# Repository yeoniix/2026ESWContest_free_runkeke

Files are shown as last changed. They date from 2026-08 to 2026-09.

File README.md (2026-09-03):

# HeatSentry TAC

**군 집단훈련 온열위험 대응 시스템** — 감지 · 자가 개입 · 관제 전파를 한 장비에서 완결하는
현장 안전 웨어러블 시스템

> 제24회 임베디드SW경진대회 자유공모 출품작 · 팀 **런크크(RUNKEKE)**
> 개발기간 2026.07.01 ~ 2026.09.03

```
센서 취득 → RiskIndex → 상태 판정(FSM) → 자동 냉각 → 재평가 → (미회복 시 상향) → SOS → 감사 로그
```

HeatSentry는 손목 웨어러블의 생체신호, 허리의 능동 냉각, 로컬 게이트웨이, 관제 대시보드를
하나의 폐루프로 묶는다. 위험도가 임계를 넘으면 **누구의 지시도 기다리지 않고** 벨트가 팬을
돌리고 장갑 OLED·진동으로 착용자에게 알리며, 같은 판정 결과가 LoRa로 관제까지 전파된다.

> [!IMPORTANT]
> **RiskIndex와 피부온도는 의료 진단값이 아니다.** 현장 경보와 냉각 우선순위를 정하기 위한
> 상대 위험도이며, 열사병 의심 증상·의식 변화·무응답이 있으면 장치 점수와 무관하게 현장
> 응급절차가 항상 우선한다.

---

스크린샷 2026-09-03 오전 10 31 55

스크린샷 2026-09-03 오전 10 32 06

스크린샷 2026-09-03 오전 10 32 22

스크린샷 2026-09-03 오전 10 32 43

스크린샷 2026-09-03 오전 10 33 26

스크린샷 2026-09-03 오전 10 33 35

스크린샷 2026-09-03 오전 10 33 56

스크린샷 2026-09-03 오전 10 34 07

스크린샷 2026-09-03 오전 10 34 17

스크린샷 2026-09-03 오전 10 34 25

스크린샷 2026-09-03 오전 10 34 34

스크린샷 2026-09-03 오전 10 34 41

스크린샷 2026-09-03 오전 10 34 51

스크린샷 2026-09-03 오전 10 35 01

스크린샷 2026-09-03 오전 10 35 11

스크린샷 2026-09-03 오전 10 35 21

스크린샷 2026-09-03 오전 10 35 31

스크린샷 2026-09-03 오전 10 35 39

스크린샷 2026-09-03 오전 10 35 48

스크린샷 2026-09-03 오전 10 35 59

## 목차

1. [왜 만들었나](#왜-만들었나)
2. [시스템 구성](#시스템-구성)
3. [저장소 구조](#저장소-구조)
4. [빠르게 돌려보기](#빠르게-돌려보기)
5. [실물 하드웨어 연동](#실물-하드웨어-연동)
6. [RiskIndex 계산](#riskindex-계산)
7. [상태 판정(FSM)](#상태-판정fsm)
8. [게이트웨이 API](#게이트웨이-api)
9. [데이터 무결성과 감사 로그](#데이터-무결성과-감사-로그)
10. [보안·운영 설정](#보안운영-설정)
11. [시험](#시험)
12. [안전 경계와 적용 범위](#안전-경계와-적용-범위)
13. [알려진 차이와 남은 작업](#알려진-차이와-남은-작업)
14. [문서 · 팀](#문서--팀)

---

## 왜 만들었나

2024년 5월 육군 12사단 훈련병 사망 사고에서, 우리 팀은 집단훈련 온열 질환 사고를 세 가지
문제로 정의했다.

| 문제 | 이 저장소의 대응 |
| --- | --- |
| **주관적 오판** — 개인의 위험 신호가 "꾀병"으로 묵살될 여지 | 센서값과 RiskIndex를 위·변조 탐지 가능한 해시체인 로그로 관제에 전송해, 주관이 아닌 수치로 판단하게 한다 |
| **자가진단 실패** — 열 스트레스는 당사자가 스스로 인지하기 어렵다 | 장갑 손등 OLED에 상태를 상시 표시하고, 임계 초과 시 진동 모터가 즉시 작동한다 |
| **초기 개입 수단 부재** — 이상을 감지해도 즉시 취할 물리적 수단이 없다 | 지휘관 개입 이전에 허리 장착형 냉각 팬을 자동 구동한다 |

개인의 통제 아래 놓인 기존 웨어러블과 달리, **집단 통제가 필요한 특수 환경**에서 쓸 수 있는
반응형 경보 시스템을 목표로 했다.

### 기존 개인용 웨어러블과의 차이

| 비교 항목 | 일반적인 개인 경고형 웨어러블 | HeatSentry |
| --- | --- | --- |
| 위험 대응 | 알림 제공 후 종료 | OLED·진동 경고 → 팬 1개 → 팬 2개 → 관제 전파 |
| 통신 두절 | 서버 연결이 끊기면 관제·대응 제한 | 벨트가 로컬에서 계속 판정하고 팬을 독립 제어 |
| 판정 구조 | 서버 판정에 의존 | 벨트가 단독 판정자 — 게이트웨이는 재계산하지 않고 전달만 하며, 해석 불가 값은 오류로 남긴다 |
| 센서 고장 | 누락값으로 위험을 과소평가 | 고장 센서 제외 + 가중치 재정규화 + `SENSOR_LIMITED` 별도 표시 |
| 통신 효율 | Wi-Fi·서버 연결 중심 | 35바이트 LoRa 패킷으로 생체·상태·GPS 원거리 전송 |
| 사후 기록 | 수정 가능한 일반 로그 | SHA-256 해시체인으로 최초 변경 지점 탐지 |

---

## 시스템 구성

```
 ┌──────────────────┐  ESP-NOW   ┌──────────────────┐   LoRa    ┌──────────────┐  HTTP  ┌───────────┐
 │   손목 노드       │ ─ 28B/1s ─▶│    벨트 노드      │─ 35B/2s ─▶│ LoRa 수신기   │───────▶│ 게이트웨이 │
 │  ESP32 Dev       │◀─ 12B/0.5s │  Heltec ESP32-S3 │  922.3MHz └──────────────┘        │ FastAPI   │
 │                  │            │                  │                                   └─────┬─────┘
 │ MAX30102  심박    │            │ 로컬 FSM 판정     │                                    WS /ws/live
 │ TMP117    피부온도 │            │ ATGM336H GPS     │                                    REST /api/v2
 │ GSR       피부전도 │            │ 비상 버튼         │                                         │
 │ SSD1306   OLED   │            │ 팬 ×2 (PWM)      │                                   ┌─────▼─────┐
 │ 진동 모터         │            │ LoRa 송신         │                                   │  대시보드  │
 └──────────────────┘            └──────────────────┘                                   │ React+Vite│
                                                                                        └───────────┘
   판정하지 않는다.                실물 경로의 단독 판정자.            위험도를 다시 계산하지        현장 팬을 제어할 수 없고
   벨트가 회신한 상태를             LoRa가 끊겨도 팬과 OLED를          않고 저장·전파만 한다.       응급도 해제할 수 없다.
   띄우고 경고 시 진동.             혼자 계속 구동한다.                                           확인 기록만 남긴다.
```

### 통신 규격

| 링크 | 내용 | 주기 | 정의 위치 |
| --- | --- | --- | --- |
| ESP-NOW 손목→벨트 | `SensorPacket` 28B (bpm, temp, gsr, gsrDiff, ir, finger, seq) | 1초 | [firmware/glove_esp32/glove_esp32.ino](firmware/glove_esp32/glove_esp32.ino) |
| ESP-NOW 벨트→손목 | `DisplayPacket` 12B (state, cause, fanPercent, bpm, skinTemp, flags) | 0.5초 | [firmware/glove_esp32/display_protocol.h](firmware/glove_esp32/display_protocol.h) |
| LoRa 벨트→수신기 | `TelemetryPacket` 35B · SF7 · BW 125kHz · CR 4/5 · 922.3MHz. 생체값 + GPS + 벨트 판정(state·cause·냉각단계·위험도) | GPS fix 시 단축 | [firmware/lora_get/esplora_get.ino](firmware/lora_get/esplora_get.ino) · [glove_packets.py](heatsentry/common/glove_packets.py) |
| HTTP 브리지→게이트웨이 | `POST /ingest/telemetry` (TelemetryV2 JSON) | 패킷마다 | [heatsentry/common/schema.py](heatsentry/common/schema.py) |
| WebSocket 게이트웨이→UI | `/ws/live` — `snapshot` / `telemetry` / `event` / `command_ack` | ≤1초 | [heatsentry/server/ws.py](heatsentry/server/ws.py) |

35바이트 안에 벨트의 판정까지 담기 위해, DHT 제거로 비게 된 두 16비트 자리를 재활용한다.

```
state_cause_word = (DeviceState << 8) | CauseCode
stage_risk_word  = (CoolingStage << 8) | RiskIndex
```

패킷 크기는 펌웨어의 `static_assert`와 파이썬 디코더가 서로 검증하며,
[tests/test_display_protocol_sync.py](tests/test_display_protocol_sync.py)가 장갑·벨트 두
헤더 파일과 파이썬 enum의 코드 정의가 어긋나지 않는지 확인한다.

> [!WARNING]
> 현재 `firmware/belt_heltec/belt_heltec.ino`에 **벨트 펌웨어가 없다** — 장갑 스케치로
> 덮어써진 상태다. LoRa 송신 주기·송신 출력 등 벨트 측 수치는 저장소에서 확인할 수 없다.
> [알려진 차이](#알려진-차이와-남은-작업) 참고.

### 서브시스템 책임

| 서브시스템 | 책임 | 코드 |
| --- | --- | --- |
| SU-W 손목 노드 | 센서 취득·품질 검사, OLED 표시, 진동 | `firmware/glove_esp32/`, `heatsentry/simulator/wrist_node.py` |
| SU-B 허리 노드 | 로컬 위험 판정, 팬 PWM 제어, GPS, 비상 버튼, LoRa 송신 | `firmware/belt_heltec/`, `heatsentry/simulator/belt_node.py` |
| SU-E 환경 노드 | EnvHeatProxy (WBGT와는 별개 지표, 시뮬레이터 전용) | `heatsentry/simulator/env_node.py` |
| SU-G 게이트웨이 | 패킷 디코딩·저장·해시체인·역할 분리·WebSocket 전파 (재판정하지 않음) | `heatsentry/server/` |
| SU-D 대시보드 | 상태 카드, 위험도 추이, GPS 지도, 이벤트·확인 기록 | `dashboard/` |

---

## 저장소 구조

파이썬 코드는 전부 `heatsentry/` 패키지 하나에 있고, 그 바깥에는 파이썬이 아닌 것만 둔다 —
임베디드 펌웨어, 웹 대시보드, 문서, 시험.

```
heatsentry/          파이썬 패키지 (pip install -e . 로 설치 가능)
├─ common/           패킷 정의·해시체인·CRC16·오류코드·게이트웨이 스키마
│  ├─ packets.py         HS_STATUS / COOL_CMD / COOL_ACK 바이너리 레이아웃, DeviceState
│  ├─ glove_packets.py   실물 35B TelemetryPacket 디코더, 벨트 상태·원인 코드
│  ├─ schema.py          TelemetryV2 (게이트웨이 ↔ 대시보드 JSON 계약)
│  └─ hash_chain.py      SHA-256 이벤트 해시체인
├─ algorithm/        위험도 판정
│  ├─ risk_config.py     가중치·임계값·냉각 단계 표 (형상관리 대상 숫자 전부)
│  ├─ risk_engine.py     RiskIndex v0.3 계산 + 품질 게이트
│  ├─ baseline.py        개인 기준선(3~5분) 생성
│  ├─ fsm.py             C0~C4 냉각 단계 · DeviceState · 명령 중재
│  ├─ hardware_adapter.py 실물 3특징 프로필용 어댑터
│  └─ display_status.py  OLED 2줄 문구 생성
├─ simulator/        결정적 노드 시뮬레이터 (실물 펌웨어의 레퍼런스 구현)
│  └─ run_demo.py        T01~T08·T10 시나리오 러너
└─ server/           게이트웨이 (FastAPI)
   ├─ main.py            앱 조립 · CORS · /ws/live
   ├─ routes_ingest.py   /ingest/* (장치 키 인증 · 시퀀스 중복 제거)
   ├─ routes_api_v2.py   /api/v2/* (역할 기반 확인·해제·내보내기·설정)
   ├─ lora_adapter.py    35B 패킷 → TelemetryV2 변환 (벨트 판정을 그대로 전달)
   ├─ state.py / db.py   메모리 상태 + SQLite 저장 + 해시체인
   └─ ws.py              WebSocket 브로드캐스트

firmware/            임베디드 C/C++
├─ glove_esp32/      장갑 ESP32 스케치 + OLED 표시 프로토콜 헤더
├─ belt_heltec/      벨트 Heltec LoRa 스케치 (로컬 판정 · 팬 제어) + 표시 프로토콜 헤더
└─ lora_get/         LoRa 수신기 스케치 (35B를 시리얼로 넘긴다)

dashboard/           React + TypeScript + Vite 관제 대시보드
docs/hardware/       실물 배선 · 핀맵 · 조립 · 브리지 연동 가이드, CAD 소스
tests/               pytest 80건
pyproject.toml       패키지 경계와 pytest 설정
requirements.txt     고정 의존성
```

임계값·가중치 같은 형상관리 대상 숫자는 [heatsentry/algorithm/risk_config.py](heatsentry/algorithm/risk_config.py)
한 파일에 모여 있다. FSM은 이 파일의 표만 읽으므로, 냉각 단계 기준을 바꿀 때 `fsm.py`는
건드리지 않는다.

---

## 빠르게 돌려보기

하드웨어 없이 시뮬레이터만으로 감지 → 냉각 → 관제 전파 폐루프 전체를 재현할 수 있다.
터미널 3개가 필요하다.

### 1) 게이트웨이 (FastAPI)

```bash
python3 -m venv .venv
source .venv/bin/activate       # Windows: .venv\Scripts\activate
pip install -r requirements.txt
uvicorn heatsentry.server.main:app --reload --port 8000
```

`http://127.0.0.1:8000/docs`에서 OpenAPI 문서를 확인할 수 있다.

### 2) 노드 시뮬레이터

```bash
# 새 터미널, 같은 가상환경
python -m heatsentry.simulator.run_demo --scenario T03 --fast
```

| 옵션 | 기본값 | 설명 |
| --- | --- | --- |
| `--scenario` | `T03` | `T01`~`T08`, `T10` 중 하나 (정의는 [scenarios.py](heatsentry/simulator/scenarios.py)) |
| `--gateway-url` | `http://127.0.0.1:8000` | 게이트웨이 주소 |
| `--device-id` | `HS-W-001` | 장치 ID |
| `--fast` | off | 3~5분 걸리는 기준선 측정을 6~9초로 단축 (**개발용**, 실제 시연에는 쓰지 않는다) |
| `--sleep` | `1.0` | tick 사이 실제 대기 시간(초). `0`이면 최대 속도 |
| `--dt` | `1.0` | tick 하나가 나타내는 시뮬레이션 시간(초) |
| `--cycles` | `3` | T10 통합 시나리오 반복 횟수 |

주요 시나리오:

| ID | 검증 내용 |
| --- | --- |
| T01 | 기준선 안정 → NORMAL 유지 |
| T02 | PPG/EDA 동시 품질 저하 → `valid_weight < 0.60` → `SENSOR_LIMITED` |
| T03 | RiskIndex ≥ 80이 10초 지속 → 냉각 C1 진입 (CTL-001) |
| T04 | 냉각 명령 ACK 손실 → 재전송 |
| T05 | 팬 과전류 → 팬 OFF (E301) |
| T06 | 90→70 회복 → 30초 후 단계 하향 |
| T07 | C2가 60초 이상 미회복 → C3, 지휘관 확인 후에만 하향 |
| T08 | 낙상+무동작+무응답 → HardTrigger → 즉시 EMERGENCY |
| T10 | 폐루프 통합 반복 + 로그 변조 시 해시체인 불일치 검출 |

### 3) 대시보드 (React + Vite)

```bash
cd dashboard
npm install
npm run dev
```

`http://localhost:5173`에서 실시간 장치 카드, RiskIndex 추이, 냉각 상태, GPS 지도,
이벤트 로그(해시체인), 확인/응급 해제 콘솔을 볼 수 있다. 우측 상단 역할 선택기로
`observer` / `commander` / `tester` / `maintainer`를 바꿔가며 권한 분리를 확인한다(HMI-001).

선택 설정 — `dashboard/.env.local`:

```bash
VITE_GATEWAY_URL=http://127.0.0.1:8000   # 기본값
VITE_KAKAO_MAP_APP_KEY=<카카오맵 JS 키>   # 없으면 지도 대신 안내 문구 표시
```

---

## 실물 하드웨어 연동

### 부품

| 노드 | 부품 | 역할 |
| --- | --- | --- |
| 손목 | ESP32 Dev Module | 메인 MCU |
| | MAX30102 | PPG · 심박 |
| | TMP117 | 피부 온도 |
| | GSR Sensor | 피부 전도 |
| | SSD1306 OLED 128×64 | 상태 표시 |
| | 진동 모터 | 경고 |
| 벨트 | Heltec ESP32-S3 (LoRa 915) | 로컬 판정 · LoRa 송신 |
| | ATGM336H | GPS 측위 |
| | 12mm 버튼 | 비상 입력 |
| | 40×40mm Fan ×2 | 능동 냉각 (PWM 5kHz · 8bit) |

기구부는 Fusion 360으로 설계해 3D 프린팅했다 — 듀얼 팬 모듈, 유도판, 상부 덕트, 팬 교체가
가능한 분리형 하우징. CAD 파라메트릭 소스는 [docs/hardware/cad/](docs/hardware/cad/)에 있다.

### 펌웨어 빌드

Arduino IDE 2.x + ESP32 Arduino Core로 세 스케치를 각각 업로드한다.

| 스케치 | 보드 |
| --- | --- |
| [firmware/glove_esp32/glove_esp32.ino](firmware/glove_esp32/glove_esp32.ino) | ESP32 Dev Module |
| [firmware/belt_heltec/belt_heltec.ino](firmware/belt_heltec/belt_heltec.ino) | Heltec WiFi LoRa 32 (V3) — **현재 소스 유실 상태** |
| [firmware/lora_get/esplora_get.ino](firmware/lora_get/esplora_get.ino) | Heltec WiFi LoRa 32 (V3) |

벨트와 수신기의 LoRa 파라미터(922.3MHz · SF7 · BW 125kHz · CR 4/5)는 **반드시 동일해야**
한다. 자세한 배선·핀맵·조립 순서는 [docs/hardware/hardware_integration_kr.md](docs/hardware/hardware_integration_kr.md).

### 수신기 → 게이트웨이 브리지

LoRa 수신기 스케치는 35바이트를 검증한 뒤 시리얼로 넘긴다. 파이썬 쪽에는 이를 관제
텔레메트리로 바꾸는 어댑터가 준비돼 있다.

```python
import requests
from heatsentry.server.lora_adapter import LoRaTelemetryAdapter

adapter = LoRaTelemetryAdapter()

def handle_packet(payload: bytes, rssi: int, snr: int) -> None:
    telemetry = adapter.convert(payload, rssi_dbm=rssi, snr_db=snr)
    requests.post("http://127.0.0.1:8000/ingest/telemetry",
                  json=telemetry.model_dump(), timeout=3).raise_for_status()
```

> [!NOTE]
> **USB 시리얼을 읽어 위 함수를 호출하는 상주 프로세스는 아직 저장소에 없다.** 디코더·어댑터·
> 게이트웨이 수신단은 모두 구현·시험되어 있고, 남은 것은 시리얼 루프 하나다. 권장 시리얼 한 줄
> 형식과 전체 예제는 [docs/hardware/hardware_integration_kr.md](docs/hardware/hardware_integration_kr.md) 12장에 있다.

---

## RiskIndex 계산

RiskIndex v0.3 엔진은 **시뮬레이터 경로(손목 노드)** 가 쓴다. 실물 경로에서는 벨트가 자체
위험점수를 계산해 패킷에 실어 보내므로 게이트웨이가 이 엔진을 다시 돌리지 않는다
([판정 주체](#판정-주체--경로에-따라-다르다) 참고).

세 개 이상의 생체·환경 특징을 각각 0~1로 정규화해 가중 평균한다. 핵심은 **분모가 상수가
아니라 "지금 살아있는 가중치의 합"**이라는 점이다. 센서 하나가 죽어도 0으로 희석되지 않고,
남은 센서끼리 다시 정규화한다.

```
RiskIndex = 100 × Σ(wᵢ · qᵢ · featureᵢ) / Σ(wᵢ · qᵢ)

  w       가중치
  q       센서 품질 (0~1, 게이트 미달이면 0)
  feature 0~1로 정규화(clamp)한 특징

valid_weight = Σ(wᵢ · qᵢ)
  < 0.60 → SENSOR_LIMITED 플래그
  = 0    → 판정 불가 (risk_index = 255)
```

### 가중치 — 두 개의 프로필

`risk_config.py`는 설계 기준과 실물 하드웨어, 두 벌의 가중치를 갖는다.

| 특징 | 정규화 | `DEFAULT_CONFIG`<br>(설계 · 시뮬레이터) | `HARDWARE_CONFIG`<br>(실물 3특징) |
| --- | --- | --- | --- |
| `HR_dev` 심박 편차 | (BPM − 기준선) / MAD ÷ 4 | 0.25 | **0.45** |
| `SkinTemp_slope` 온도 상승률 | (°C/분) ÷ 0.3 | 0.20 | **0.37** |
| `EDA_delta` 발한 변화 | GSR 변화량 ÷ 300 | 0.10 | **0.18** |
| `HRV_suppression` | RMSSD 억제 | 0.10 | 0 — 패킷에 RMSSD 없음 |
| `ActivityLoad` | IMU 활동량 | 0.15 | 0 — IMU 미탑재 |
| `EnvHeatProxy` | 환경 열부하 | 0.20 | 0 — DHT 센서 제거 |

실물 패킷에는 6특징 중 3개가 오지 않는다(DHT는 하드웨어에서 제거됐고, 그 자리는 벨트 판정
전송에 재활용된다). 설계 가중치를 그대로 쓰면 살아있는 가중치 합이
0.55로 `min_valid_weight`(0.60)에 항상 미달해 실물 장비가 무조건 `SENSOR_LIMITED`로 보고되는
문제가 있었다. 그래서 남은 3특징에 가중치를 비례 재분배해 합이 1.00이 되게 했다. RiskIndex는
어차피 `valid_weight`로 나눠 재정규화하므로 **점수 자체는 달라지지 않고**, `valid_weight`의
의미만 달라진다 — 이제 0.60 미달은 "설계상 없는 센서" 때문이 아니라 손가락 이탈·온도 정지 같은
**실제 품질 저하**일 때만 발생한다.

### 품질 게이트

| 코드 | 조건 | 제외되는 특징 |
| --- | --- | --- |
| `E101` | PPG 품질 < 70 | `HR_dev`, `HRV_suppression` |
| `E102` | EDA 접촉 손실 (품질 < 40) | `EDA_delta` |
| `E103` | 피부온도 3초 이상 갱신 없음 | `SkinTemp_slope` |
| `E105` | 환경 센서 품질 < 50 | `EnvHeatProxy` |

게이트를 통과하면 `q = 품질/100`으로 비례 반영하고, 미달하면 `q = 0`으로 계산에서 제외한 뒤
오류코드를 `active_errors`에 남긴다. 개인 기준선은 유효 착용 3~5분 구간에서 생성하며, 기준선이
없으면 RiskIndex를 계산하지 않고 `BASELINE` 상태로 보고한다.

---

## 상태 판정(FSM)

상태 코드는 펌웨어·게이트웨이·대시보드가 **하나의 정의를 공유한다.** 벨트가 보낸 값을
관제가 다른 뜻으로 읽는 일이 없도록, `firmware/*/display_protocol.h`의 enum과
`heatsentry/common/glove_packets.py`의 파이썬 enum이 이름·값 모두 같아야 하며
[tests/test_display_protocol_sync.py](tests/test_display_protocol_sync.py)가 이를 검사한다.

### DeviceState — 지금 어떤 상황인가

| 값 | 상태 | 조건 |
| --- | --- | --- |
| 0 | `BOOT` | 부팅 |
| 1 | `BASELINE` | 기준선 미완성 → RiskIndex 미계산 |
| 2 | `NORMAL` | C0이면서 경고 없음 |
| 3 | `CAUTION` | 경고 활성 (진입 60 · 10초 / 해제 55 · 30초) |
| 4 | `COOLING` | 냉각 단계가 C1 이상 |
| 5 | `EMERGENCY` | 비상 래치 걸림 |
| 6 | `SENSOR_CHECK` | 손가락 미착용 · BPM 0 · 데이터 무효 |

### 냉각 단계 — 팬을 얼마나 트는가

상태와 별개로 `CoolingStageCode`(C0~C4)가 함께 전송된다. 정의는
[risk_config.py](heatsentry/algorithm/risk_config.py)의 `CoolingStageConfig` 표 하나뿐이다.

| 단계 | 진입 조건 | 해제 조건 | 팬 |
| --- | --- | --- | --- |
| C0 | 최하단 | — | 0% |
| C1 | risk ≥ 80 · 10초 | risk < 70 · 30초 | 50% |
| C2 | risk ≥ 90 · 10초 | risk < 80 · 30초 | 100% |
| C3 | risk ≥ 90 · 60초 | risk < 85 · 60초 **+ 지휘관 확인** | 100% |
| C4 | risk ≥ 95 · 즉시 | **자동 해제 없음** | 100% |

C2와 C3가 같은 100%인 것은, 실제 블로워의 저출력 구간이 체감 냉각 효과가 작아 현장 제어를
OFF → 50% → 100% 두 출력 단계로 단순화했기 때문이다. 두 단계의 구분은 출력이 아니라 **위험
지속 시간과 경보 수준**에 있다.

`fsm.py`는 단계 이름조차 코드에 두지 않는다 — 최하단·최상단과 "자동 해제 조건이 없는
비상 단계"를 모두 위 표에서 유도하므로, 냉각 기준을 바꿀 때 고칠 파일은 `risk_config.py`
하나다. [tests/test_fsm.py](tests/test_fsm.py)가 임계값을 바꾼 설정으로 이를 회귀 검증한다.

Fail-safe: 링크 10초 두절 시 저하 모드, 팬 안전 타이머 60초, 명령 ACK 타임아웃 500ms ·
최대 3회 재전송.

### 판정 주체 — 경로에 따라 다르다

| 경로 | 판정 주체 | 게이트웨이의 역할 |
| --- | --- | --- |
| **실물 하드웨어** (LoRa 35B) | **벨트 노드** | 재계산하지 않고 전달만 한다 |
| **시뮬레이터** (HTTP) | 손목 노드 (RiskIndex v0.3 + FSM) | 재계산하지 않고 저장·전파만 한다 |

두 경로 모두 게이트웨이는 **판정을 다시 내리지 않는다.** 특히 실물 경로에서 벨트가 단독
판정자인 이유는, LoRa가 끊겨도 팬과 장갑 OLED가 계속 동작해야 하기 때문이다. 현장에서 실제로
팬을 돌린 근거와 관제 화면의 값이 갈리면 사고 조사에서 어느 쪽도 신뢰할 수 없게 되므로,
`lora_adapter.py`는 벨트가 보낸 `DeviceState` · `CoolingStage` · `RiskIndex` · `Cause`를
그대로 옮긴다.

대신 **값이 해석 불가일 때 조용히 넘어가지 않는다.**

| `active_errors` | 조건 | 처리 |
| --- | --- | --- |
| `STATE_INVALID` | 모르는 상태 코드 | `SENSOR_CHECK`으로 낮춘다 |
| `COOLING_STAGE_INVALID` | 모르는 냉각 단계 | C0으로 낮춘다 |
| `RISK_INVALID` | 위험도가 0~100 범위 밖 | `risk_index = 255`(판정 불가) |
| `SENSOR_CHECK` | 손가락 미착용 · 장갑 데이터 무효 | 그대로 표시 |

### 비상 상태 해제

`hard_trigger`(낙상+무동작 / SOS)로 걸린 래치는 **자동으로 풀리지 않는다.**
`close_emergency()`는 `/api/v2/emergency/{id}/close` 핸들러가 현장 확인자 정보와 함께
명시적으로 호출할 때만 실행되며, 이 엔드포인트는 `commander` 역할을 요구한다. 해제 직후에도
팬을 즉시 끄지 않고 한 단계 아래(C3)를 유지한다.

## 게이트웨이 API

| 메서드 | 경로 | 권한 | 설명 |
| --- | --- | --- | --- |
| `POST` | `/ingest/telemetry` | 장치 키 | 텔레메트리 수신 (시퀀스 증가분만 반영) |
| `POST` | `/ingest/event` | 장치 키 | 장치 이벤트 → 해시체인 기록 |
| `POST` | `/ingest/command_ack` | 장치 키 | 냉각 명령 ACK |
| `GET` | `/api/v2/devices` | 전체 | 장치별 최신 상태 |
| `GET` | `/api/v2/events` | 전체 | 이벤트 로그 (해시 포함) |
| `GET` | `/api/v2/alerts` | 전체 | 경보 목록 |
| `GET` | `/api/v2/emergency` | 전체 | 응급 목록 |
| `POST` | `/api/v2/alerts/{id}/ack` | `commander` | 알림 확인 |
| `POST` | `/api/v2/emergency/{id}/close` | `commander` | 응급 해제 (현장 확인자 기록 필수) |
| `POST` | `/api/v2/export` | `tester` | 이벤트 CSV/JSON 내보내기 |
| `PUT` | `/api/v2/config` | `maintainer` | 설정 변경 (HMAC-SHA256 서명 검증) |
| `WS` | `/ws/live` | observer 수준 | `snapshot` → `telemetry`/`event`/`command_ack` 스트림 |

역할은 `X-HS-Role`, 행위자는 `X-HS-Actor`, 장치 키는 `X-HS-Device-Key` 헤더로 전달한다.

> [!WARNING]
> `heatsentry/server/auth.py`의 역할 검사는 **프로덕션 인증이 아니다.** 대회 MVP 단계에서
> "권한이 분리되어 있어야 한다"는 구조를 먼저 세워둔 헤더 기반 placeholder이며, 실사용 전에는
> 서명된 토큰으로 교체해야 한다. `/api/v2/config` PUT만은 요구사항상 HMAC 서명 검증을 최소
> 구현해 두었다.

---

## 데이터 무결성과 감사 로그

모든 경보·명령·ACK·확인 기록은 SQLite에 저장되면서 해시체인으로 묶인다.

```
event_hash = SHA256( previous_hash || canonical_json(event_without_hash) )
canonical_json: UTF-8 · sorted keys · no whitespace · 소수점 6자리 고정
genesis previous_hash = "0" * 64
```

체인 중간의 한 건이라도 수정되면 그 지점부터 해시가 어긋나므로 **최초 변경 지점을 특정할 수
있다.** T10 시나리오가 실제로 로그를 변조해 불일치 검출을 확인한다. `/api/v2/export`로
`seq`, `gateway_utc`, `event_hash`, `previous_hash`를 포함한 CSV/JSON을 내보내 외부에서 재검증할
수 있고, 내보내기 행위 자체도 감사 기록에 남는다.

기본 DB 경로는 `heatsentry/heatsentry_gateway.db`이며 `HEATSENTRY_DB_PATH`로 바꿀 수 있다.
보존 정책과 스키마는 [db.py](heatsentry/server/db.py), 체인 계산은 [hash_chain.py](heatsentry/common/hash_chain.py)에 있다.

---

## 보안·운영 설정

실장 환경에서는 장치별 비밀키를 반드시 등록한다. **키가 비어 있으면 시뮬레이터 호환을 위한
개발 모드이며 `/ingest/*` 인증이 수행되지 않는다.**

```bash
export HEATSENTRY_DEVICE_KEYS='{"HS-W-001":"change-this-device-secret"}'
export HEATSENTRY_DEVICE_KEY='change-this-device-secret'   # 시뮬레이터 실행 터미널
export HEATSENTRY_CONFIG_SECRET='change-this-config-secret'
export HEATSENTRY_CORS_ORIGINS='http://127.0.0.1:5173'
export HEATSENTRY_DB_PATH='/var/lib/heatsentry/gateway.db'
```

| 환경변수 | 기본값 | 용도 |
| --- | --- | --- |
| `HEATSENTRY_DEVICE_KEYS` | `{}` (인증 없음) | 장치 ID → 비밀키 JSON 맵 |
| `HEATSENTRY_DEVICE_KEY` | 없음 | 시뮬레이터가 보낼 키 |
| `HEATSENTRY_CONFIG_SECRET` | `dev-only-insecure-secret` | `/api/v2/config` HMAC 키 |
| `HEATSENTRY_CORS_ORIGINS` | `http://127.0.0.1:5173,http://localhost:5173` | 허용 오리진 (쉼표 구분) |
| `HEATSENTRY_DB_PATH` | `heatsentry/heatsentry_gateway.db` | SQLite 경로 |

장치 키가 설정되면 모든 `/ingest/*` 요청은 `X-HS-Device-Key`가 일치해야 한다. 텔레메트리는
장치별 `sequence`가 증가할 때만 반영되므로, 재전송이 현재 상태나 감사 이벤트를 중복으로
덮어쓰지 않는다.

---

## 시험

```bash
# 파이썬 — 80건
pytest -q

# 대시보드 — 타입체크 · 빌드 · 린트
cd dashboard
npm run build
npx eslint .
```

| 파일 | 건수 | 검증 대상 |
| --- | --- | --- |
| `test_fsm.py` | 13 | 냉각 단계 승급·강등, 히스테리시스, 비상 래치, 명령 중재, 임계값 하드코딩 금지 |
| `test_gateway_api.py` | 10 | REST v2, 역할 분리, 장치 키, 시퀀스 중복 제거 |
| `test_hardware_risk_adapter.py` | 8 | 실물 3특징 프로필, 가중치 재정규화 |
| `test_scenarios_integration.py` | 8 | T01~T10 폐루프 통합 |
| `test_lora_adapter.py` | 9 | 35B → TelemetryV2 변환, 벨트 판정 무손실 전달, 해석 불가 값 검출 |
| `test_packets.py` | 7 | HS_STATUS / COOL_CMD / COOL_ACK 바이트 레이아웃 · CRC16 |
| `test_risk_engine.py` | 6 | RiskIndex 공식, 품질 게이트, `valid_weight` |
| `test_glove_packets.py` | 6 | 35B TelemetryPacket 디코딩, 상태·원인·냉각단계·위험도 워드 분해 |
| `test_display_protocol_sync.py` | 5 | 장갑·벨트 헤더와 파이썬 enum의 상태·냉각단계·원인 코드 일치 |
| `test_display_status.py` | 4 | OLED 2줄 문구 결정성 |
| `test_hash_chain.py` | 4 | 정규화 JSON, 체인 연결, 변조 검출 |
| **합계** | **80** | |

---

## 안전 경계와 적용 범위

### 안전 경계

1. **대시보드는 EMERGENCY를 자동 해제할 수 없다.** 관제의 "해제" 버튼은 감사 기록을 남기고
   `commander` 확인 절차를 거치며, 현장의 물리적 확인이 전제된다.
2. **"알림 확인"과 "응급 해제"는 다른 버튼·다른 권한이다.**
3. **자동 냉각이 실패해도 수동 정지와 구조 절차는 항상 유지된다.**
4. **RiskIndex/피부온도는 의료 진단값이 아니다** — 현장 응급절차가 항상 장치 판정보다 우선한다.
5. **관제는 현장 팬을 원격 제어하지 않는다.** 팬 제어 권한은 벨트 노드에만 있다.

### 적용 범위 — 훈련 안전 한정

HeatSentry는 **지정된 훈련장에서 훈련 시간 중에만** 운용하는 훈련 안전 장비다. 실작전·경계
근무 상황에서의 상시 착용과 위치 전송은 설계 단계부터 비적용 범위로 고정했다.

- **RF 노출** — LoRa 상시 송신은 방향 탐지로 역추적될 수 있어, 실전에서는 부대의 위치와 규모를
  스스로 노출하는 수단이 된다. 이미 공개된 고정 구역인 훈련장에서만 쓰면 이 위험이 사라진다.
- **해킹 위험** — 장치 정보가 유출되면 저장된 위치 이력이 함께 넘어간다. 위치 데이터를 훈련
  세션 단위로만 유지하는 이유다.
- **감시 전용 방지** — 위치·생체 데이터는 안전 목적을 벗어나는 순간 감시 도구가 되기에, 구조
  대상자를 찾는 데 필요한 최소 정보로 범위를 좁혔다.

민간 산업 안전(고온 작업장·옥외 건설·소방)으로 확장할 경우, 위치 계층을 옵션으로 분리하고
데이터 보관 기간과 열람 권한을 사업장 안전관리 규정에 맞춰 설정한다. 안전 목적 외 사용을 막는
것이 확장의 전제 조건이다.

---

## 알려진 차이와 남은 작업

투명성을 위해 현재 코드와 설계 문서 사이의 차이를 명시한다.

| 항목 | 현황 |
| --- | --- |
| LoRa 시리얼 브리지 | 디코더·어댑터·수신단은 구현·시험 완료. USB 시리얼을 읽는 상주 프로세스는 미구현 (예제 코드는 HW 가이드 12장) |
| `auth.py` 역할 검사 | 헤더 기반 placeholder. 실사용 전 서명 토큰으로 교체 필요 |
| **벨트 펌웨어 소스 유실** | `firmware/belt_heltec/belt_heltec.ino`가 장갑 스케치로 덮어써져 LoRa·GPS·팬 제어·비상 버튼 코드가 저장소에 없다. 마지막 정상본은 커밋 `b2daff8`이나 옛 상태코드를 써서 현재 헤더로는 빌드되지 않는다 — **복구 필요** |
| `WARNING` → `CAUTION` 진입 임계 60 | 기준 문서에 숫자가 없어 v1.0 값을 이어받은 설계 기본값. 실측 데이터 확보 시 CR로 조정하고 `RISK_CONFIG_VERSION`을 올린다 |
| `EnvHeatProxy` / `HRV` / `ActivityLoad` | 시뮬레이터에만 존재. DHT 제거·RMSSD 미산출·IMU 미탑재로 실물에서는 가중치 0 |
| `HardwareRiskAdapter` | 게이트웨이가 재판정을 그만두면서 실행 경로에서 빠졌다. 시험으로만 유지 중이며, 벨트 없이 원시 센서만 받는 구성으로 되돌릴 때 필요하다 |
| `SU-E` 환경 노드 | `heatsentry/simulator/env_node.py`가 어디서도 import되지 않는다. 설계 문서상 서브시스템이라 남겨 뒀다 |
| `pyserial` 의존성 | 시리얼 브리지 추가를 위해 미리 고정해 둔 것으로 현재 코드에서는 사용하지 않는다 |

### 발전 방향

- **IMU 추가** — 낙상 감지·행동 분류를 정식 기능으로 편입하고 실측 데이터로 임계값 보정
- **냉각 방식 보완** — 팬 구동에 더해 PCM(상변화물질) 모듈을 허리 노드에 추가
- **다중 착용자 확장** — 한 게이트웨이가 다수 노드를 수용하도록 스케줄링·패킷 충돌 제어 확장

### 개발 단계

| 단계 | 목표 | 상태 |
| --- | --- | --- |
| P0 기능증명 | 신호·팬 확인 | 완료 |
| P1 대회 MVP | 8주 폐루프 시연 | 알고리즘·게이트웨이·대시보드·시뮬레이터 폐루프 완성, 실물 3노드 동작 확인. 시리얼 브리지 자동화가 남음 |
| P2 현장 확장 | 다중 인원·장거리 | 범위 밖 |

---

## 문서 · 팀

### 설계 문서

| 문서 | 내용 |
| --- | --- |
| [docs/hardware/hardware_integration_kr.md](docs/hardware/hardware_integration_kr.md) | 실물 배선·핀맵·조립·브리지 연동 가이드 |
| [docs/hardware/cad/](docs/hardware/cad/) | 냉각 하우징 CAD 소스·STL·BOM·출력 체크리스트 |

설계 근거와 수치의 1차 출처는 기준선 문서(`HS-PDD-002`, `HS-SIID-002`)이며, 코드에서
그 근거가 필요한 자리에는 해당 절·표 번호를 주석으로 달아 두었다. 알고리즘·상태 판정·
패킷 규격은 이 README와 아래 코드가 기준이다.

| 대상 | 코드 |
| --- | --- |
| RiskIndex 공식·품질 게이트 | [risk_engine.py](heatsentry/algorithm/risk_engine.py) |
| 가중치·임계값·냉각 단계 표 | [risk_config.py](heatsentry/algorithm/risk_config.py) |
| 상태 판정·명령 중재 | [fsm.py](heatsentry/algorithm/fsm.py) |
| 패킷 바이트 레이아웃 | [packets.py](heatsentry/common/packets.py) · [glove_packets.py](heatsentry/common/glove_packets.py) |
| 게이트웨이 데이터 계약 | [schema.py](heatsentry/common/schema.py) |
| 시험 벡터 T01~T10 | [scenarios.py](heatsentry/simulator/scenarios.py) |

기준선 문서는 `HS-PDD-002`(제품개발 상세설계서)와 `HS-SIID-002`(시스템 통합·인터페이스
명세서) v2.0이다. 인터페이스 정의가 코드와 어긋나면 **인터페이스는 먼저 동결하고 구현을
교체 가능하게 한다**는 원칙을 따른다.

### 개발 환경

| 구분 | 내용 |
| --- | --- |
| Embedded | Arduino IDE 2.x · ESP32 Arduino Core · C/C++ |
| Backend | Python 3.11+ · FastAPI · Uvicorn |
| Frontend | React 19 · TypeScript · Vite |
| Database | SQLite + SHA-256 Hash Chain |
| Communication | ESP-NOW · LoRa · UART · I2C · HTTP/REST · WebSocket |
| Design / CAD | Autodesk Fusion 360 |

### 업무 분담 — 팀 런크크(RUNKEKE)

| 팀원 | 담당 |
| --- | --- |
| **박주영** (전자공학과) | 장갑 센서 회로 설계·배선, ESP32 펌웨어 구현, 생체·환경 센서 측정 및 보정, 시뮬레이터 및 단위·통합·현장시험 |
| **이영재** (전자공학과) | Heltec 기반 벨트 노드 회로 설계, GPS 연동, 냉각 팬·모터 드라이버 제어, 벨트 하우징 및 냉각 구조 제작 |
| **박솔희** (전자공학과) | LoRa 수신기 펌웨어 구현, 패킷 송수신·CRC16 검증, 센서 품질·통합 오류코드 관리, 35B 텔레메트리 패킷 생성·송신 |
| **정여은** (소프트웨어융합학과) | 게이트웨이 서버 구축(FastAPI·SQLite·WebSocket), RiskIndex 엔진 및 안전 상태기계 설계·구현, 관제 대시보드 개발, 해시체인 감사 로그 |

### 참고자료

부품 사양과 안전·환경 지표의 1차 출처는 `HS-PDD-002`/`HS-SIID-002`의 참고자료 절(NIOSH 열
스트레스 권고, NIOSH/OSHA WBGT 안내, ESP32/MAX30102/TMP117/GSR/BQ24074/Heltec ESP32-S3
데이터시트)을 따른다. 구매·인증·현장 적용 전 최신 개정본을 재확인한다.

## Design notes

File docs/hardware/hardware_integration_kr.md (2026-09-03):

# HeatSentry 실물 하드웨어·통신·대시보드 통합 가이드

> 기준일: 2026-08-30  
> 소프트웨어 저장소: <https://github.com/yeoniix/heatsentry-tac>  
> 확인한 저장소 기준 커밋: `5dc9e50` (`feat: add GPS map to dashboard`)  
> 실물 펌웨어: `firmware/glove_esp32/glove_esp32.ino`, `firmware/glove_esp32/display_protocol.h`, `firmware/belt_heltec/belt_heltec.ino`

이 문서는 HeatSentry의 실물 손목 장치와 벨트 장치가 무엇을 측정하고, 어떻게 서로 통신하며,
벨트가 만든 데이터를 게이트웨이와 관제 대시보드까지 전달하는지를 재현 가능한 수준으로 설명한다.

HeatSentry는 의료 진단 장비가 아니다. 표시되는 심박, 피부온도, 환경값과 위험 상태는 현장 안전을
보조하기 위한 정보이며, 의식 저하·무응답·열질환 의심 증상이 있으면 장치 상태와 관계없이 현장
응급 절차를 우선해야 한다.

문서 작성에 사용한 최종 로컬 파일의 SHA-256은 다음과 같다. 이후 코드가 바뀌었는지 판단할 때 이
값과 비교할 수 있다.

| 파일 | SHA-256 |
| --- | --- |
| `firmware/glove_esp32/glove_esp32.ino` | `437461259AECBA061A72F6E6CFEF52A70EAAD10C1633B41B96C7D7FB89A8D724` |
| `firmware/glove_esp32/display_protocol.h` | `A1D9E8AB7BEECF084C23CE42059D87059CD24C51C56F21A4AC380A4DD90F9C4C` |
| `firmware/belt_heltec/belt_heltec.ino` | `69452A081011E0B85B8E0B8BC0BC1AA6AE87151DD0DEA38D6D0E974C9B4C9C0A` |

---

## 1. 현재 구현 범위부터 정확히 이해하기

### 1.1 실물 하드웨어에서 구현된 기능

- 손목 ESP32가 MAX30102, TMP117, GSR 센서를 읽는다.
- 손목 ESP32가 센서값을 1초마다 ESP-NOW 브로드캐스트로 벨트에 보낸다.
- 벨트 ESP32가 손목 데이터, GPS 데이터, 비상 버튼을 한곳에 모은다.
  (DHT11 환경 데이터는 센서 불량으로 현재 구성에서 빠졌다 — 11.4 참고)
- 상태 판단은 손목이 아니라 벨트에서 수행한다.
- 벨트가 상태를 0.5초마다 손목으로 다시 보내고, 손목 OLED가 그 결과만 표시한다.
- 손목은 경고 상태를 받으면 진동한다.
- 벨트는 피부온도 또는 비상 상태에 따라 팬을 켜거나 끈다.
- 벨트는 손목·GPS·팬·비상 정보와 자신의 상태 판정을 35바이트 LoRa 패킷으로 2초마다 송신한다.

### 1.2 GitHub 저장소에서 구현된 기능

- Python 기반 RiskIndex/FSM 알고리즘, ESP32 3특징 어댑터와 결정적 시뮬레이터
- FastAPI 게이트웨이의 `/ingest/*`, `/api/v2/*`, `/ws/live`
- SQLite 텔레메트리·이벤트 저장 및 이벤트 해시체인
- React/Vite 실시간 관제 대시보드
- 장치 상태 카드, 위험도 추이, 경보 확인, 응급 확인 기록, GPS 카카오맵
- 실물 벨트의 35바이트 LoRa 패킷을 푸는 Python 디코더와 RiskIndex 어댑터
  (`heatsentry/common/glove_packets.py`, `heatsentry/algorithm/hardware_adapter.py`, `heatsentry/server/lora_adapter.py`)

### 1.3 아직 자동으로 연결되지 않은 부분

현재 저장소에는 **LoRa 전파를 실제로 수신하여 35바이트를 Python에 넘기는 베이스 수신기/시리얼
브리지 프로그램이 없다.** `heatsentry/server/lora_adapter.py`는 수신기가 넘긴 payload를 관제
Telemetry로 바꾸지만, USB 시리얼을 읽는 실행 프로세스는 아직 추가해야 한다.

또한 현재 35바이트 LoRa 패킷에는 센서값과 플래그만 있고 다음 값이 없다.

- 벨트가 판정한 `state`
- 판정 원인 `cause`
- 정확한 `fanPercent`
- `risk_index`

따라서 현재 패킷만으로는 벨트가 판정한 `WARNING`, `DANGER`, `HIGH_RISK`를 그대로 알 수는 없다.
다만 `heatsentry/server/lora_adapter.py`는 수신한 실물값으로 3특징 RiskIndex를 계산해 관제용
상태를 만들 수 있다. 이 문서의 12장에서 다음 두 연결 방법을 설명한다.

1. 펌웨어를 바꾸지 않고 35바이트를 사용하여 원시 센서·GPS와 제한된 상태를 표시하는 방법
2. 벨트를 상태 판단의 유일한 기준으로 유지하기 위해 LoRa 패킷에 상태 필드를 추가하는 권장 방법

저장소의 기존 기준 문서는 시뮬레이터 기준으로 손목 노드가 RiskIndex/FSM을 계산하고 BLE 또는
HTTP 등가 경로를 사용한다고 설명한다. 실물 최종 설계는 벨트가 상태를 계산하고 ESP-NOW+LoRa를
사용하므로 `README.md`도 이 문서와 함께 갱신해야
역할 설명이 충돌하지 않는다.

---

## 2. 전체 시스템 구조

```mermaid
flowchart LR
    subgraph W[손목 ESP32]
        MAX[MAX30102\nIR/심박]
        TMP[TMP117\n피부온도]
        GSR[GSR\n피부전도]
        OLED[SSD1306 OLED\n128x64]
        VIB[진동 모터]
    end

    subgraph B[벨트 Heltec ESP32-S3 + LoRa]
        FSM[상태 판정 FSM]
        DHT[DHT11\n환경온도/습도]
        GPS[ATGM336H\nGPS]
        BTN[비상 버튼]
        FAN[팬 드라이버/팬]
        LTX[LoRa 송신]
    end

    subgraph G[베이스·게이트웨이]
        LRX[LoRa 수신기\n현재 추가 필요]
        BRIDGE[35B 디코더·JSON 변환\n현재 추가 필요]
        API[FastAPI 게이트웨이]
        DB[(SQLite)]
    end

    subgraph D[관제 대시보드]
        CARD[장치 상태 카드]
        TREND[위험도 추이]
        MAP[GPS 카카오맵]
        EVENT[이벤트/확인 기록]
    end

    MAX --> WTX[SensorPacket 생성]
    TMP --> WTX
    GSR --> WTX
    WTX -- "ESP-NOW 1초 / 28B" --> FSM
    DHT --> FSM
    GPS --> FSM
    BTN --> FSM
    FSM --> FAN
    FSM -- "ESP-NOW 0.5초 / DisplayPacket 12B" --> OLED
    FSM --> VIB
    FSM --> LTX
    LTX -- "LoRa 922.3MHz 2초 / 35B" --> LRX
    LRX --> BRIDGE
    BRIDGE -- "HTTP POST /ingest/telemetry" --> API
    API --> DB
    API -- "WebSocket /ws/live" --> CARD
    API --> TREND
    API --> MAP
    API --> EVENT
```

핵심 원칙은 다음과 같다.

- 센서 취득은 손목과 벨트에서 나누어 수행한다.
- 착용자에게 즉시 필요한 상태 판단과 팬 제어는 벨트에서 수행한다.
- 손목 OLED는 자체 판단을 하지 않고 벨트가 보낸 상태를 표시한다.
- 서버와 대시보드가 끊겨도 손목↔벨트 로컬 폐루프는 계속 작동한다.
- 대시보드는 수신·저장·표시·확인 기록을 담당하며, 현장 팬을 직접 제어하지 않는다.

---

## 3. 저장소 배치

실물 코드와 시스템 코드를 역할별로 다음과 같이 배치한다.

```text
heatsentry-tac/
├─ firmware/    ESP32 펌웨어, 통신 계약, 시뮬레이터
├─ algorithm/   위험도 계산 및 상태 판단
├─ common/      공통 데이터 구조와 패킷 처리
├─ server/      FastAPI Gateway
├─ dashboard/   React 관제 Dashboard
├─ docs/        시스템·하드웨어 문서 및 CAD
└─ tests/       자동화 테스트
```

Arduino IDE는 폴더명과 메인 `.ino` 파일명이 같을 때 다루기 편하다. 업로드를 위해 파일명을
다음과 같이 정리했다.

| 이전 로컬 파일 | 현재 저장소 위치 |
| --- | --- |
| `gloves_ESP32/gloves_ESP32.ino` | `firmware/glove_esp32/glove_esp32.ino` |
| `gloves_ESP32/display_protocol.h` | `firmware/glove_esp32/display_protocol.h` |
| `esplora_sen/esplora_sen.ino` | `firmware/belt_heltec/belt_heltec.ino` |

`firmware/glove_esp32/display_messages.py`는 화면 문구를 설계할 때 사용한 Python 초안이며 현재 ESP32 런타임에서 호출되지 않는다.
최종 OLED 문구의 기준은 `firmware/glove_esp32/glove_esp32.ino`의 `updateDisplay()`다.

---

## 4. 하드웨어 구성

### 4.1 손목 장치

| 부품 | 역할 | 코드에서 사용하는 인터페이스 |
| --- | --- | --- |
| ESP32 Dev Module | 센서 취득, ESP-NOW, OLED, 진동 | Wi-Fi/ESP-NOW, I2C, ADC, GPIO |
| MAX30102 | IR 기반 손가락 감지 및 심박 계산 | I2C, 기본 주소 `0x57` |
| TMP117 | 피부 접촉 온도 | I2C, 일반적인 기본 주소 `0x48` |
| GSR 센서 | 피부전도 원시값 | ADC |
| SSD1306 OLED 128x64 I2C | 벨트가 계산한 상태 표시 | I2C, 주소 `0x3C` |
| 소형 진동 모터 + 구동회로 | 경고 촉각 알림 | GPIO 제어 |

### 4.2 벨트 장치

| 부품 | 역할 | 코드에서 사용하는 인터페이스 |
| --- | --- | --- |
| Heltec ESP32-S3 LoRa 계열 보드 | 상태 계산, 팬, GPS/DHT, ESP-NOW, LoRa | Wi-Fi/ESP-NOW, UART, GPIO, 내장 LoRa |
| DHT11 | 환경온도·습도 | 단일 DATA GPIO |
| ATGM336H | 위치, 고도, 속도, 위성 수 | UART 9600bps |
| 비상 버튼 | 수동 SOS | `INPUT_PULLUP` GPIO |
| 2채널 모터 드라이버 | 팬 전원 구동 | GPIO 두 개 |
| 냉각 팬 2개 | 착용자 냉각 | 모터 드라이버 출력 |

벨트 코드는 GPIO47을 사용하므로 일반 ESP32가 아니라 해당 핀이 있는 ESP32-S3 계열을 전제로 한다.
Heltec 보드 모델이 바뀌면 먼저 보드 핀맵과 `LoRaWan_APP.h` 지원 여부를 다시 확인해야 한다.

### 4.3 베이스 장치

대시보드까지 실물 데이터를 전달하려면 다음이 추가로 필요하다.

- 벨트와 같은 LoRa 설정을 사용하는 수신 보드
- 수신 보드와 게이트웨이 PC 또는 Raspberry Pi 사이의 USB 시리얼 연결
- 시리얼에서 받은 35바이트를 `TelemetryV2` JSON으로 변환하는 브리지 프로세스
- FastAPI 서버와 React 대시보드를 실행할 PC 또는 Raspberry Pi

---

## 5. 배선

### 5.1 손목 ESP32 배선

MAX30102, TMP117, SSD1306 OLED는 같은 I2C 버스를 공유한다.

| 장치 단자 | ESP32 핀 | 비고 |
| --- | ---: | --- |
| MAX30102 SDA | GPIO21 | I2C 공용 SDA |
| MAX30102 SCL | GPIO22 | I2C 공용 SCL |
| TMP117 SDA | GPIO21 | I2C 공용 SDA |
| TMP117 SCL | GPIO22 | I2C 공용 SCL |
| OLED SDA | GPIO21 | I2C 공용 SDA |
| OLED SCL | GPIO22 | I2C 공용 SCL |
| OLED VCC | 3.3V | 모듈 사양 확인 |
| OLED GND | GND | 모든 장치 공통 GND |
| GSR AO | GPIO34 | 12비트 ADC 입력, 0~4095 |
| 진동 모터 구동 입력 | GPIO25 | 모터를 GPIO에 직접 연결하지 말 것 |

전원은 사용 중인 센서 모듈 사양을 우선한다. ESP32 GPIO는 3.3V 로직이며 ADC 입력에 3.3V를 넘는
전압을 넣으면 안 된다. 진동 모터는 순간 전류와 역기전력이 있으므로 N-MOSFET 또는 트랜지스터,
보호 다이오드, 모터용 전원을 사용하고 ESP32와 GND를 공통으로 묶는다.

I2C 주소가 기본값일 때는 `0x57`, `0x48`, `0x3C`로 서로 충돌하지 않는다. 문제가 생기면 I2C
스캐너로 실제 주소를 먼저 확인한다. 여러 모듈의 풀업 저항이 병렬로 연결되어 전체 풀업 저항이 너무
낮아지지 않게 주의한다.

### 5.2 벨트 배선

| 장치 단자 | 벨트 GPIO/전원 | 비고 |
| --- | ---: | --- |
| DHT11 DATA | GPIO33 | 최종 변경 핀 |
| DHT11 VCC | 3.3V | 모듈 사양 확인 |
| DHT11 GND | GND | 공통 GND |
| GPS TX | GPIO38 | ESP32의 RX |
| GPS RX | GPIO39 | ESP32의 TX |
| GPS VCC | 3.3V | ATGM336H 모듈 사양 확인 |
| GPS GND | GND | 공통 GND |
| 비상 버튼 한쪽 | GPIO7 | `INPUT_PULLUP` |
| 비상 버튼 다른 쪽 | GND | 누르면 LOW |
| 드라이버 A-1A | GPIO6 | 팬 1 제어 |
| 드라이버 A-1B | GND | 현재 코드 배선 정의 |
| 드라이버 B-1A | GPIO47 | 팬 2 제어 |
| 드라이버 B-1B | GND | 현재 코드 배선 정의 |
| 모터 드라이버 VCC | 5V | 팬·드라이버 사양 확인 |
| 모터 드라이버 GND | 공통 GND | ESP32 GND와 반드시 공통 |

팬을 ESP32 GPIO에서 직접 구동하면 안 된다. 팬 전류는 모터 드라이버와 별도 전원에서 공급하고,
GPIO6/GPIO47은 제어 신호만 보낸다.

### 5.3 DHT11 노이즈 대책

확인된 증상은 팬 모터가 동작할 때 DHT11 읽기가 실패하는 것이었다. 현재 적용한 해결은 DHT11의
VCC와 GND 사이에 약 `100uF` 캐패시터를 추가하는 것이다.

```text
3.3V ----+---------- DHT11 VCC
         |
       + | 100uF 전해 캐패시터
         |
GND  ----+---------- DHT11 GND
```

- 전해 캐패시터의 `+`는 3.3V, `-`는 GND에 연결한다.
- 캐패시터는 DHT11 모듈 가까이에 둔다.
- 고주파 성분을 줄이기 위해 `0.1uF` 세라믹 캐패시터를 병렬로 추가하면 더 안정적이다.
- 팬 드라이버 전원에도 별도의 벌크 캐패시터를 두고 센서 전원선과 모터 전원선을 가능한 한 분리한다.
- 팬 배선은 센서 DATA/GPS 안테나와 떨어뜨리고, 모든 GND는 짧고 확실하게 공통화한다.
- 순간적인 Wi-Fi/ESP-NOW 간섭으로 DHT11이 가끔 실패할 수 있으므로 코드는 3회 재시도한다.

캐패시터는 전원 변동을 줄이는 대책이다. DHT11이 뜨거워지거나 탄 냄새가 나면 전원을 즉시 끄고
VCC/GND 역결선, 5V 오인가, 단락 여부를 확인한 뒤 센서를 교체해야 한다.

### 5.4 GPS 설치 대책

- GPS 안테나는 Heltec LoRa 안테나와 보드에서 가능하면 10cm 이상 이격한다.
- 최초 위치 고정은 실내보다 하늘이 열린 실외에서 시험한다.
- `GPS chars > 0`은 UART 문자가 들어온다는 뜻일 뿐 위치 고정 성공을 뜻하지 않는다.
- 위치가 유효하고 마지막 갱신 후 15초 미만일 때만 `GPS_FIX` 플래그가 켜진다.

---

## 6. 개발 환경과 라이브러리

### 6.1 공통

- Arduino IDE 2.x
- Espressif ESP32 Arduino Core
- 시리얼 모니터: `115200 baud`

손목은 Arduino IDE 보드를 `ESP32 Dev Module`로 사용한 업로드가 확인됐다. 벨트는 실제 Heltec
ESP32-S3 LoRa 보드 모델과 일치하는 보드 항목을 선택해야 한다.

### 6.2 손목 라이브러리

| 헤더 | 설치 라이브러리 |
| --- | --- |
| `WiFi.h`, `esp_now.h`, `Wire.h` | ESP32 Arduino Core 내장 |
| `MAX30105.h`, `heartRate.h` | SparkFun MAX3010x Pulse and Proximity Sensor Library |
| `SparkFun_TMP117.h` | SparkFun TMP117 Arduino Library |
| `Adafruit_GFX.h` | Adafruit GFX Library |
| `Adafruit_SSD1306.h` | Adafruit SSD1306 |

### 6.3 벨트 라이브러리

| 헤더 | 설치/출처 |
| --- | --- |
| `WiFi.h`, `esp_now.h`, `esp_wifi.h` | ESP32 Arduino Core 내장 |
| `DHTesp.h` | DHTesp |
| `HT_TinyGPS++.h` | Heltec 패키지에 포함된 TinyGPS++ 계열 헤더 |
| `LoRaWan_APP.h` | 해당 Heltec 보드 패키지/라이브러리 |

`HT_TinyGPS++.h`와 `LoRaWan_APP.h`는 일반 ESP32 보드 패키지에 없을 수 있다. 컴파일 오류가 나면
임의의 다른 LoRa 라이브러리로 바꾸기 전에 실제 Heltec 보드용 Arduino 패키지를 설치한다.

---

## 7. 손목 펌웨어 동작

### 7.1 초기화 순서

1. 시리얼 115200 시작
2. I2C를 SDA GPIO21, SCL GPIO22로 시작
3. ESP-NOW 시작, 수신 콜백 등록, 브로드캐스트 peer 등록
4. OLED 주소 `0x3C` 초기화
5. 진동 모터 GPIO25 출력 설정
6. ADC를 12비트로 설정
7. TMP117 초기화
8. MAX30102 초기화 및 LED/샘플 설정
9. GSR 기준선 측정
10. 시작 진동 120ms

OLED 초기화 실패 시에는 화면만 포기하고 센서·통신을 계속한다. 반면 TMP117 또는 MAX30102 초기화가
실패하면 현재 코드는 `while (1)`로 정지한다.

### 7.2 MAX30102 심박 처리

- IR 원시값이 `50000`을 넘으면 손가락이 있다고 판단한다.
- SparkFun `checkForBeat()`로 박동 시점을 검출한다.
- 박동 간격으로 순간 BPM을 계산한다.
- `45 < BPM < 180`인 값만 유효하게 사용한다.
- 최근 최대 8개의 유효 BPM 평균을 `beatAvg`로 보낸다.
- 손가락이 떨어지면 BPM과 평균 버퍼를 0으로 초기화한다.

이 값은 의료기기 수준의 심박값이 아니며, 센서 접촉압·움직임·주변광의 영향을 받는다.

### 7.3 TMP117 피부온도

TMP117은 1초마다 읽고 `tempC`에 저장한다. 이 값이 벨트 팬 및 현재 단순 상태 FSM의 핵심 입력이다.

### 7.4 GSR

- 시작할 때 50회 기준선 샘플을 모은다.
- 각 샘플은 ADC를 10번 읽어 평균낸 값이다.
- 사용자가 움직이지 않은 상태에서 기준선을 잡아야 한다.
- 이후 200ms마다 필터된 값을 읽는다.
- `gsrDiff = gsrValue - gsrBaseline`로 전송한다.

현재 벨트의 단순 FSM은 GSR을 LoRa로 전달하지만 상태 전이에 사용하지 않는다.

### 7.5 손목의 역할 제한

손목은 상태를 계산하지 않는다. 손목이 수행하는 판단은 센서 전처리와 다음 두 가지 표시 보조뿐이다.

- 벨트 상태 패킷이 3초 이상 오지 않으면 `LINK LOST / CHECK BELT / ESP-NOW WAIT`
- 벨트 상태가 `WARNING` 이상이고 `EMERGENCY` 이하이면 3초 간격으로 짧게 두 번 진동

---

## 8. 손목↔벨트 ESP-NOW 통신

### 8.1 통신 방향

| 방향 | 패킷 | 주기 | 목적 |
| --- | --- | ---: | --- |
| 손목 → 벨트 | `SensorPacket` | 1000ms | BPM, 피부온도, GSR, IR, 손가락 상태 |
| 벨트 → 손목 | `DisplayPacket` | 500ms | 벨트가 계산한 상태, 원인, 팬, 표시값 |

손목은 `FF:FF:FF:FF:FF:FF`로 센서 패킷을 브로드캐스트한다. 벨트는 수신 패킷의 송신 MAC이
코드에 등록된 `34:98:7A:BD:7A:2C`일 때만 받아들인다. 벨트는 같은 MAC으로 표시 패킷을
유니캐스트 회신한다.

### 8.2 손목 MAC 확인과 변경

손목 보드가 바뀌면 벨트의 `gloveMac[]`도 바꿔야 한다. 손목에서 다음 코드로 STA MAC을 확인한다.

```cpp
WiFi.mode(WIFI_STA);
Serial.println(WiFi.macAddress());
```

예를 들어 출력이 `34:98:7A:BD:7A:2C`라면 벨트에 다음과 같이 입력한다.

```cpp
uint8_t gloveMac[] = {0x34, 0x98, 0x7A, 0xBD, 0x7A, 0x2C};
```

### 8.3 `SensorPacket` 현재 레이아웃

현재 구조체에는 `packed`가 없다. ESP32 GCC의 일반 정렬에서는 크기가 28바이트이며 `bool` 뒤에
3바이트 패딩이 들어간다.

| 오프셋 | 크기 | C++ 형식 | 필드 | 의미 |
| ---: | ---: | --- | --- | --- |
| 0 | 4 | `int` | `bpm` | 평균 심박 |
| 4 | 4 | `float` | `temp` | 피부온도 °C |
| 8 | 4 | `int` | `gsr` | GSR ADC 값 |
| 12 | 4 | `int` | `gsrDiff` | 기준선 대비 차이 |
| 16 | 4 | `long` | `ir` | MAX30102 IR 원시값 |
| 20 | 1 | `bool` | `finger` | 손가락 감지 |
| 21 | 3 | 패딩 | — | 구조체 정렬 |
| 24 | 4 | `unsigned long` | `seq` | 송신 순번 |

손목과 벨트의 `SensorPacket` 선언은 필드 순서와 형식이 한 글자도 다르면 안 된다. 한쪽만
`packed`로 바꾸면 크기가 달라져 벨트에서 `SIZE ERROR`가 발생한다. 현재 코드를 유지한다면 양쪽에
다음 검사를 추가하는 것이 안전하다.

```cpp
static_assert(sizeof(SensorPacket) == 28, "SensorPacket ABI changed");
```

장기적으로는 패딩에 의존하지 않도록 고정 폭 형식(`uint8_t`, `int16_t`, `uint32_t`)과 `packed`,
magic, version을 넣은 새 프로토콜로 교체하는 편이 좋다.

### 8.4 `DisplayPacket` 12바이트 레이아웃

`display_protocol.h`와 벨트 코드의 구조체가 반드시 같아야 한다.

| 오프셋 | 크기 | 필드 | 변환/의미 |
| ---: | ---: | --- | --- |
| 0 | 2 | `magic` | `0xD15A`, 전송 바이트는 `5A D1` |
| 2 | 1 | `version` | 현재 `1` |
| 3 | 1 | `state` | `StateCode` |
| 4 | 1 | `cause` | `CauseCode` |
| 5 | 1 | `fanPercent` | 두 팬 채널의 최댓값. 현재 0 또는 100 |
| 6 | 1 | `bpm` | 0~255 |
| 7 | 2 | `skinTemp_x100` | `값 / 100 = °C` |
| 9 | 1 | `flags` | 아래 표 참고 |
| 10 | 2 | `seq` | 표시 패킷 순번 |

`DisplayPacket.flags`는 현재 다음과 같다.

| bit | 의미 |
| ---: | --- |
| 0 | 손가락 감지 |
| 1 | 비상 상태 |
| 2 | 팬 ON |
| 3 | 최근 10초 안에 손목 패킷 수신 |

수신 손목은 길이 12바이트, magic `0xD15A`, version `1`을 모두 통과한 패킷만 사용한다.

### 8.5 ESP-NOW 채널과 보안

양쪽 모두 `channel = 0`, `encrypt = false`다. 현재는 두 장치가 AP에 연결되지 않고 STA 모드만
사용하므로 가까운 거리의 시험에서 동작하지만, 한쪽을 Wi-Fi AP에 연결하면 채널이 바뀌어 통신이
끊길 수 있다. 현장 버전에서는 다음을 권장한다.

- 고정 채널을 명시하고 양쪽을 같은 채널로 설정
- peer 암호화 또는 애플리케이션 인증 추가
- DisplayPacket 수신 시 magic뿐 아니라 송신 MAC도 검증
- 송신 완료 콜백, 손실률, 마지막 정상 sequence를 시리얼에 기록

---

## 9. 벨트 상태 판단과 팬 제어

### 9.1 상태 코드

| 값 | 상태 | 손목 OLED 1줄 |
| ---: | --- | --- |
| 0 | `STATE_BOOT` | `BOOT` |
| 1 | `STATE_BASELINE` | `BASELINE` |
| 2 | `STATE_NORMAL` | `NORMAL` |
| 3 | `STATE_WARNING` | `WARNING` |
| 4 | `STATE_COOLING` | `COOLING` |
| 5 | `STATE_DANGER` | `DANGER` |
| 6 | `STATE_HIGH_RISK` | `HIGH RISK` |
| 7 | `STATE_EMERGENCY` | `EMERGENCY` |
| 8 | `STATE_SENSOR_CHECK` | `SENSOR CHECK` |

현재 코드에는 9개 상태가 모두 정의되어 있지만, 실제 `makeDisplayStatus()`가 생성하는 상태는
`BOOT`, `BASELINE`, `NORMAL`, `WARNING`, `DANGER`, `EMERGENCY`, `SENSOR_CHECK` 7개다.
`COOLING`과 `HIGH_RISK`는 화면 준비는 되어 있으나 현재 조건식에서는 생성되지 않는다.

### 9.2 현재 FSM 판정 우선순위

위에서 먼저 만족한 조건이 최종 상태가 된다.

`makeDisplayStatus()`가 0.5초마다 호출되며, 위에서 먼저 만족한 조건이 최종 상태가 된다.

| 우선 | 조건 | 결과 상태 | 원인 |
| ---: | --- | --- | --- |
| 1 | 비상 버튼 상태 활성 | `EMERGENCY` | `NONE` |
| 2 | 손목 데이터 없음/10초 초과, Finger NO, BPM ≤ 0 | `SENSOR_CHECK` | `SENSOR` (기준선 초기화) |
| 3 | 기준선 수집 3분 미만 | `BASELINE` | `NONE` |
| 4 | 아래 위험점수 표에 따름 | — | `determineCause()` |

#### 벨트 자체 위험점수 `calculateRisk()`

RiskIndex v0.3을 포팅한 것이 아니라, 벨트가 통신 두절 상태에서도 단독 판단할 수 있도록 만든
**구간별 가산식**이다. 유효 표본이 10개 미만이면 0을 반환한다.

| 항목 | 조건 | 가산 |
| --- | --- | ---: |
| BPM 편차 | 기준선 대비 `≥ 40` | +60 |
| | 기준선 대비 `≥ 25` | +40 |
| 피부온도 | 편차 `≥ 0.9°C` 또는 상승률 `≥ 0.20°C/분` | +55 |
| | 편차 `≥ 0.5°C` 또는 상승률 `≥ 0.10°C/분` | +35 |
| GSR | 절대 편차 `≥ max(10, 기준선/20)` 또는 상대 변화 `≥ 15%` | +25 |

합계를 0~100으로 clamp한다. `risk ≥ 60`이 **10초 연속** 유지되면 `held10s`가 성립한다.

| 위험점수 | `held10s` 미성립 | `held10s` 성립 |
| --- | --- | --- |
| `< 40` | `NORMAL` | `NORMAL` |
| `40 ~ 59` | `CAUTION` | `CAUTION` |
| `60 ~ 84` | `CAUTION` | `COOLING_50` |
| `≥ 85` | `CAUTION` | `DANGER` |

원인 코드는 `determineCause()`가 BPM 편차 `≥ 25` → `HR_HIGH`, 피부온도 편차 `≥ 0.5` → `TEMP_UP`,
GSR 편차 초과 → `GSR_UP` 순서로 하나만 고른다.

> 게이트웨이의 RiskIndex v0.3과는 입력 특징도 임계값도 다르다. 두 판정을 하나로 합치지 않고
> 각각 보존하는 이유와 대응표는 [../api_contract.md](../api_contract.md)의 "판정이 두 벌인 이유" 참고.

### 9.3 팬 제어

두 팬을 개별 PWM 채널로 제어한다(`setFanPins(pct1, pct2)`). 냉각 1단계는 듀티를 낮추는 대신
**팬 하나만 돌리는** 방식이다 — 저출력 듀티는 체감 냉각 효과가 작기 때문이다.

| 조건 | FAN1 | FAN2 |
| --- | --- | --- |
| 비상 활성 | 100% | 100% |
| 손목 데이터 없음/10초 초과, Finger NO, BPM ≤ 0 | OFF | OFF |
| 기준선 수집 중 | OFF | OFF |
| `NORMAL` / `CAUTION` (risk < 60 또는 10초 미유지) | OFF | OFF |
| `COOLING_50` (risk 60~84, 10초 유지) | **100%** | OFF |
| `DANGER` (risk ≥ 85, 10초 유지) | 100% | 100% |

> **이름 주의:** `STATE_COOLING_50`의 `50`은 PWM 듀티 50%가 아니라 **팬 2개 중 1개**를 뜻한다.
> `DisplayPacket.fanPercent`는 두 채널의 최댓값이므로 이 단계에서도 `100`이 전달된다. 따라서
> 관제의 `cooling.actual_pwm`만으로는 1단계와 2단계를 구분할 수 없고, `raw.belt_state`를 함께
> 봐야 한다.

### 9.4 비상 버튼의 정확한 동작

버튼을 누르면 즉시 `emergencyActive = true`가 되고 팬이 켜진다. 버튼이 눌린 동안
`lastButtonPressTime`이 계속 갱신되며, 버튼에서 손을 뗀 뒤 5초가 지나면 자동으로 비상 상태가
해제된다.

즉, 현재 코드는 “5초 길게 눌러 해제”가 아니라 **“마지막으로 눌린 시점부터 5초 동안 비상 유지”**다.
GitHub 서버 문서의 “현장 물리 확인 전까지 EMERGENCY 래치 유지” 정책과 정확히 맞추려면 향후
별도의 해제 동작을 구현해야 한다.

---

## 10. 손목 OLED 표시

OLED는 `SSD1306 128x64`, I2C 주소 `0x3C`를 사용한다. 벨트에서 받은 상태가 3초 안에 갱신됐을
때만 정상 화면을 표시한다.

| 벨트 상태 | 1줄 | 2줄 |
| --- | --- | --- |
| `BOOT` | `BOOT` | `STARTING` |
| `BASELINE` | `BASELINE` | `STAY STILL` |
| `NORMAL` | `NORMAL` | `HR <bpm> T <temp>C` |
| `WARNING` | `WARNING` | 원인 문자열 |
| `COOLING` | `COOLING` | `FAN <percent>% <cause>` |
| `DANGER` | `DANGER` | `FAN 100% <cause>` |
| `HIGH_RISK` | `HIGH RISK` | `FAN 100%` |
| `EMERGENCY` | `EMERGENCY` | `SOS FAN 100%` |
| `SENSOR_CHECK` | `SENSOR CHECK` | `WEAR GLOVE` |
| 패킷 3초 초과 | `LINK LOST` | `CHECK BELT`, `ESP-NOW WAIT` |

원인 코드는 다음과 같이 표시된다.

| 원인 코드 | OLED 문구 |
| --- | --- |
| `CAUSE_HR_HIGH` | `HR HIGH` |
| `CAUSE_HR_CHANGE` | `HR CHANGE` |
| `CAUSE_TEMP_UP` | `TEMP UP` |
| `CAUSE_GSR_UP` | `GSR UP` |
| `CAUSE_HOT_ENV` | `HOT ENV` |
| `CAUSE_ACTIVE` | `ACTIVE` |
| `CAUSE_SENSOR` | `CHECK BODY` |

---

## 11. 벨트→베이스 LoRa 통신

### 11.1 무선 설정

송신기와 수신기는 다음 값이 모두 같아야 한다.

| 항목 | 값 |
| --- | ---: |
| 주파수 | `922300000 Hz` |
| 출력 | `10 dBm` |
| 대역폭 | `0` — Heltec API의 125kHz 설정 |
| Spreading Factor | `7` |
| Coding Rate | `1` — 4/5 |
| Preamble | `8` symbols |
| 고정 길이 payload | `false` |
| IQ inversion | `false` |
| Radio CRC | `true` |
| 송신 주기 | 2000ms |

주파수·출력·안테나는 실제 사용 국가의 최신 전파 규정과 해당 보드 인증 범위를 별도로 확인해야 한다.

### 11.2 `TelemetryPacket` 35바이트

구조체는 `packed`이며 ESP32 little-endian 순서로 그대로 전송된다. Python 디코더 형식은
`<HBBHBhHhIhHiiBhHB`다.

| 오프셋 | 크기 | 필드 | 단위/변환 |
| ---: | ---: | --- | --- |
| 0 | 2 | `magic` | `0xA55A`, 전송 바이트 `5A A5` |
| 2 | 1 | `version` | `1` |
| 3 | 1 | `nodeId` | 현재 `1` |
| 4 | 2 | `seq` | 0~65535 순환 |
| 6 | 1 | `bpm` | bpm |
| 7 | 2 | `skinTemp_x100` | `/100 = °C` |
| 9 | 2 | `gsr` | 0~65535 |
| 11 | 2 | `gsrDiff` | signed |
| 13 | 4 | `ir` | MAX30102 IR |
| 17 | 2 | `airTemp_x10` | **용도 변경** — `(state << 8) \| cause`. 아래 11.4 참고 |
| 19 | 2 | `humidity_x10` | 현재 미사용(항상 0) |
| 21 | 4 | `latitude_e7` | `/10,000,000 = °` |
| 25 | 4 | `longitude_e7` | `/10,000,000 = °` |
| 29 | 1 | `satellites` | 위성 수 |
| 30 | 2 | `altitude_dm` | `/10 = m` |
| 32 | 2 | `speed_x10` | `/10 = km/h` |
| 34 | 1 | `flags` | 유효성·상태 비트 |

### 11.3 LoRa flags

| bit | 마스크 | 의미 |
| ---: | ---: | --- |
| 0 | `0x01` | 최근 10초 안에 손목 데이터 수신 |
| 1 | `0x02` | DHT11 읽기 유효 — **현재 펌웨어는 세우지 않는다**(센서 제거) |
| 2 | `0x04` | GPS 위치 유효, age < 15초 |
| 3 | `0x08` | 손가락 감지 |
| 4 | `0x10` | 비상 활성 |
| 5 | `0x20` | 팬 ON |
| 6~7 | — | 예약 |

### 11.4 `airTemp_x10` 자리의 용도 변경 (DHT11 제거)

DHT11이 팬 동작 중 읽기 실패를 반복해(5.3절 노이즈 대책으로도 해결되지 않아) 현재
구성에서 제거됐다. 펌웨어는 비어 버린 16비트 자리를 **벨트가 판정한 상태·원인 코드**를
관제로 올리는 데 재활용한다.

```c
// firmware/belt_heltec/belt_heltec.ino, makeTelemetryPacket()
txData.airTemp_x10  = (state << 8) | cause;   // display_protocol.h의 StateCode/CauseCode
txData.humidity_x10 = 0;                       // 미사용
// flags의 DHT_DATA(bit1)는 세우지 않는다
```

**DHT_DATA 플래그가 이 자리의 의미를 결정한다.**

| DHT_DATA | `airTemp_x10` 해석 | `humidity_x10` |
| --- | --- | --- |
| 0 (현재) | 상위 바이트 = state, 하위 바이트 = cause | 미사용 |
| 1 (DHT 복귀 시) | 기온 × 10 | 습도 × 10 |

`heatsentry/common/glove_packets.py`는 플래그를 보고 둘 중 하나만 유효값으로 돌려주고
나머지 쪽에는 `None`을 준다. 이 규칙 덕분에 DHT를 다시 붙이면 디코더·어댑터를 고치지
않아도 환경 열부하가 자동으로 살아난다.

> 주의: 이 변경은 `version` 필드를 올리지 않고 이뤄졌다. 같은 `version=1` 패킷이
> 플래그에 따라 다른 의미를 갖는 상태이므로, 다음 패킷 개정 때는 `version`을 2로
> 올리고 상태·원인을 정식 필드로 분리하는 것이 좋다.

저장소의 `heatsentry/common/glove_packets.py` 디코더는 35바이트 구조를 정확히 풀지만 현재
`TelemetryFlags` 열거형에는 bit 0~3만 이름이 정의돼 있다. 비상·팬을 사용하려면 다음 두 값을
추가하거나 정수 마스크로 검사해야 한다.

```python
EMERGENCY = 1 << 4
FAN_ON = 1 << 5
```

### 11.4 값이 0일 때의 해석

0 자체만 보고 센서값이 유효하다고 판단하면 안 된다. 반드시 flags를 함께 본다.

- bit 0이 0이면 BPM, 피부온도, GSR, IR은 사용할 수 없는 값이다.
- bit 1이 0이면 환경온도와 습도는 사용할 수 없는 값이다.
- bit 2가 0이면 위도·경도 0은 실제 좌표가 아니라 “Fix 없음”이다.
- Finger NO 또는 BPM 0은 위험도 0이 아니라 `SENSOR CHECK` 계열로 처리해야 한다.

### 11.5 sequence 순환

LoRa `seq`는 `uint16_t`이므로 2초 주기에서 약 36.4시간 후 65535에서 0으로 돌아간다. FastAPI
게이트웨이는 기존 sequence보다 작거나 같은 요청을 중복으로 거부하므로, 브리지에서 다음과 같이
32비트 이상 확장 sequence를 만드는 것이 필요하다.

```text
last_raw가 65000 근처이고 new_raw가 0 근처이면 wrap_count += 1
extended_sequence = wrap_count * 65536 + new_raw
```

벨트가 재부팅되어 sequence가 0이 되는 경우도 있으므로 nodeId별 부팅 세션 또는 브리지의 재시작
정책을 정해야 한다.

---

## 12. LoRa 데이터를 대시보드에 연결하기

### 12.1 실제 데이터 경로

```text
벨트 Radio.Send(35B)
  → 베이스 LoRa 수신기 OnRxDone(payload, size, rssi, snr)
  → USB Serial 또는 로컬 프로세스로 35B 전달
  → common.glove_packets.decode_glove_telemetry(payload)
  → TelemetryV2 JSON 생성
  → POST http://127.0.0.1:8000/ingest/telemetry
  → FastAPI 검증·SQLite 저장·WebSocket broadcast
  → React 대시보드 즉시 갱신
```

`heatsentry/common/glove_packets.py`는 디코더일 뿐 LoRa 라디오를 직접 읽지 않는다. 수신 보드의
`OnRxDone()`은 다음 요구조건을 만족해야 한다.

1. 벨트와 LoRa 설정이 완전히 같아야 한다.
2. 수신 길이가 정확히 35인지 확인한다.
3. 첫 두 바이트가 `5A A5`인지 확인한다.
4. payload 전체, RSSI, SNR을 게이트웨이 PC에 전달한다.
5. 다음 패킷을 받도록 다시 RX 연속 모드에 들어간다.

권장 시리얼 한 줄 형식은 다음과 같다.

```json
{"payload_hex":"5aa501010100...총35바이트...","rssi_dbm":-71,"snr_db":8}
```

### 12.2 권장: 35바이트 실물값으로 RiskIndex 계산하는 브리지

수신기 프로세스는 `LoRaTelemetryAdapter`를 한 번 생성한 뒤 패킷마다 재사용한다. 이 어댑터는
3~5분 유효 착용 구간으로 개인 기준선을 만들고, **HR 편차·피부온도 상승률·GSR 변화** 세 특징으로
RiskIndex를 계산한다. HRV(패킷에 RMSSD 없음)·ActivityLoad(IMU 미탑재)·EnvHeatProxy(DHT 제거)는
없는 값으로 0을 넣지 않고 가중치를 남은 세 특징에 재분배한다(`HARDWARE_CONFIG`).

```python
import requests

from heatsentry.server.lora_adapter import LoRaTelemetryAdapter

GATEWAY_URL = "http://127.0.0.1:8000/ingest/telemetry"
adapter = LoRaTelemetryAdapter()

def handle_packet(payload: bytes, rssi: int, snr: int) -> None:
    telemetry = adapter.convert(payload, rssi_dbm=rssi, snr_db=snr)
    response = requests.post(GATEWAY_URL, json=telemetry.model_dump(), timeout=3)
    response.raise_for_status()
```

손가락 미착용, BPM 범위 밖, 장갑 데이터 무효인 경우에는 `FAULT`/`SENSOR_CHECK`으로 처리하고
RiskIndex를 계산하지 않는다. DHT가 없다는 이유만으로는 `SENSOR_LIMITED`가 되지 않는다 —
설계에서 이미 제외한 센서이기 때문이다. 유효 가중치가 0.60 아래로 떨어지는 것은 손가락 이탈
같은 실제 품질 저하일 때뿐이다.

어댑터는 벨트가 패킷에 실어 보낸 자체 판정(`raw.belt_state`/`raw.belt_cause`)을 게이트웨이
판정과 나란히 올린다. 둘이 갈리면 `active_errors`에 `BELT_STATE_MISMATCH`가 붙는다.

### 12.3 이전 raw-only 최소 브리지

다음은 수신기에서 `payload: bytes`, `rssi: int`, `snr: int`를 얻은 뒤 사용할 변환의 기준이다.
현재 패킷에는 벨트의 state와 RiskIndex가 없으므로 `risk_index=255`로 두고 제한된 상태만 추정한다.

```python
from datetime import datetime, timezone
import time
import requests

from common.glove_packets import decode_glove_telemetry

GATEWAY_URL = "http://127.0.0.1:8000/ingest/telemetry"
DEVICE_KEY = ""  # 서버에서 키를 설정했을 때만 입력

def utc_now() -> str:
    return (
        datetime.now(timezone.utc)
        .isoformat(timespec="milliseconds")
        .replace("+00:00", "Z")
    )

def convert_packet(payload: bytes, rssi: int, snr: int, extended_seq: int) -> dict:
    p = decode_glove_telemetry(payload)
    flags = int(p.flags)

    glove_ok = bool(flags & (1 << 0))
    dht_ok = bool(flags & (1 << 1))
    gps_ok = bool(flags & (1 << 2))
    finger_ok = bool(flags & (1 << 3))
    emergency = bool(flags & (1 << 4))
    fan_on = bool(flags & (1 << 5))

    active_errors = []
    if not glove_ok or not finger_ok or p.bpm <= 0:
        active_errors.append("SENSOR_CHECK")
    if not gps_ok:
        active_errors.append("GPS_NO_FIX")
    # DHT 미탑재는 오류가 아니다 — 설계에서 제외된 센서다.

    # 벨트가 판정한 상태가 패킷에 실려 온다(11.4절). 아래 표는 벨트 코드 체계를
    # 게이트웨이 DeviceState로 옮긴 것이며, 비상 버튼이 언제나 우선한다.
    belt_to_state = {
        "BOOT": "BOOT", "BASELINE": "BASELINE", "NORMAL": "NORMAL",
        "CAUTION": "WARNING", "COOLING_50": "COOLING", "DANGER": "COOLING",
        "EMERGENCY": "EMERGENCY", "SENSOR_CHECK": "FAULT",
    }
    if emergency:
        state = "EMERGENCY"
    elif not glove_ok or not finger_ok or p.bpm <= 0:
        state = "FAULT"
    elif p.belt_state is not None:
        state = belt_to_state[p.belt_state.name]
    else:
        state = "NORMAL"

    return {
        "schema_version": "2.0",
        "gateway_utc": utc_now(),
        "device_id": f"HS-W-{p.node_id:03d}",
        "monotonic_ms": int(time.monotonic() * 1000),
        "state": state,
        "risk_index": 255,
        "valid_weight": 1.0 if glove_ok and finger_ok else 0.0,
        "quality": {
            "ppg": 100 if glove_ok and finger_ok and p.bpm > 0 else 0,
            "skin": 100 if glove_ok else 0,
            "eda": 100 if glove_ok else 0,
            "imu": 0,
        },
        "signals": {
            "hr_bpm": p.bpm if glove_ok else 0,
            "skin_c": p.skin_temp_c if glove_ok else 0.0,
            "activity": "UNKNOWN",
        },
        "cooling": {
            "requested": 4 if emergency else (2 if fan_on else 0),
            "actual_pwm": 100 if fan_on else 0,
            "current_ma": 0,
        },
        "contributions": {},
        "active_errors": active_errors,
        "raw": {
            "gsr": p.gsr if glove_ok else None,
            "gsr_diff": p.gsr_diff if glove_ok else None,
            "ir": p.ir if glove_ok else None,
            "air_temp_c": p.air_temp_c,          # DHT 미탑재 시 None
            "humidity_percent": p.humidity_percent,
            "belt_state": p.belt_state.name if p.belt_state else None,
            "belt_cause": p.belt_cause.name if p.belt_cause else None,
            "belt_fan_on": fan_on,
            "finger_detected": finger_ok,
            "glove_data": glove_ok,
            "dht_data": dht_ok,
            "gps_fix": gps_ok,
            "latitude": p.latitude if gps_ok else None,
            "longitude": p.longitude if gps_ok else None,
        },
        "radio": {"rssi_dbm": rssi, "snr_db": snr},
        "config_version": "hardware-mvp-1",
        "sequence": extended_seq,
    }

def post_telemetry(data: dict) -> None:
    headers = {"X-HS-Device-Key": DEVICE_KEY} if DEVICE_KEY else {}
    response = requests.post(GATEWAY_URL, json=data, headers=headers, timeout=3)
    response.raise_for_status()
```

이 방식으로 장치 카드의 BPM, 피부온도, GSR, 환경온도·습도, Finger, RSSI, GPS와 지도는 표시할
수 있다. 그러나 `WARNING`과 `DANGER`, 정확한 RiskIndex는 패킷에 없으므로 복원할 수 없다.

### 12.4 벨트 판정을 그대로 대시보드에 띄우는 권장 확장

“상태는 벨트에서만 계산한다”는 설계를 유지하려면 LoRa 패킷에 최소 다음 4바이트를 추가한다.

```cpp
uint8_t state;       // StateCode
uint8_t cause;       // CauseCode
uint8_t fanPercent;  // 0~100
uint8_t riskIndex;   // 0~100, 계산 전/불가 255
```

현재 35바이트 뒤에 붙이면 version 2의 총 길이는 39바이트가 된다. 이때 반드시 다음을 함께 변경한다.

1. 벨트 `TelemetryPacket`에 네 필드를 추가하고 `version = 2`로 올린다.
2. `static_assert(sizeof(TelemetryPacket) == 39)`로 확인한다.
3. `heatsentry/common/glove_packets.py`가 version/길이에 따라 v1 35B와 v2 39B를 각각 해석하게 한다.
4. 브리지는 패킷의 state/cause/fan/risk를 `TelemetryV2`로 그대로 변환한다.
5. GitHub `heatsentry/common/schema.py`와 `dashboard/src/types/device.ts`에 필요한 상태를 추가한다.

현재 서버/대시보드의 상태 이름은 다음 7개만 허용한다.

```text
BOOT, BASELINE, NORMAL, WARNING, COOLING, EMERGENCY, FAULT
```

실물 벨트의 상태를 손실 없이 표시하려면 다음 3개도 허용하고 UI 라벨/색상을 정의한다.

```text
DANGER, HIGH_RISK, SENSOR_CHECK
```

수정 대상은 다음과 같다.

| 파일 | 필요한 변경 |
| --- | --- |
| `heatsentry/common/schema.py` | `DeviceStateName` Literal 확장 |
| `dashboard/src/types/device.ts` | `DeviceState`, 순서, 한국어 라벨 확장 |
| `dashboard/src/components/DeviceCard.tsx` | 상태별 카드 CSS 분류 확장 |
| `heatsentry/server/state.py` | 어떤 상태에서 alert/emergency를 열지 정책 확정 |
| 테스트 | 새 상태 JSON 수용과 WebSocket 표시 검증 |

반대로 저장소의 7상태 체계를 유지하려면 `DANGER/HIGH_RISK`를 `COOLING`으로, `SENSOR_CHECK`를
`FAULT + active_errors=["SENSOR_CHECK"]`로 매핑할 수 있다. 이 방식은 구현은 간단하지만 벨트 상태의
세부 정보가 사라진다.

---

## 13. FastAPI 게이트웨이 동작

### 13.1 입력

브리지는 다음 주소로 `TelemetryV2` JSON을 보낸다.

```http
POST /ingest/telemetry
Content-Type: application/json
X-HS-Device-Key: <장치 키를 설정한 경우>
```

`heatsentry/server/routes_ingest.py`가 Pydantic `TelemetryV2`로 자료형과 범위를 검증한다. 장치 키 설정이
비어 있으면 개발 모드로 인증 없이 받으며, 실제 운용에서는 `HEATSENTRY_DEVICE_KEYS`를 설정한다.

### 13.2 저장과 중복 제거

`heatsentry/server/state.py`의 `GatewayStore.ingest_telemetry()`가 다음을 수행한다.

1. 같은 device_id의 마지막 sequence와 비교
2. 새 sequence가 더 크지 않으면 `duplicate_ignored`
3. 최신 장치 상태를 메모리에 갱신
4. SQLite에 텔레메트리와 마지막 장치 상태 저장
5. WebSocket으로 `{"type":"telemetry","data":...}` 전송
6. 이전 state와 다르면 `STATE_CHANGE` 이벤트 생성
7. 이벤트에 이전 해시를 연결하여 해시체인 저장
8. WARNING/COOLING이면 경보, EMERGENCY이면 응급 레코드 생성

기본 SQLite 파일은 `server/heatsentry_gateway.db`이며 `HEATSENTRY_DB_PATH`로 변경할 수 있다.

### 13.3 대시보드 출력

대시보드는 시작할 때 `ws://127.0.0.1:8000/ws/live`에 연결한다.

- 연결 직후 서버는 최신 장치와 최근 이벤트 50개의 `snapshot`을 보낸다.
- 이후 새 텔레메트리는 `telemetry`, 이벤트는 `event` 메시지로 즉시 전달된다.
- WebSocket이 끊기면 `/api/v2/devices`와 `/api/v2/events`를 1.5초마다 REST 폴링한다.
- 장치별 최근 유효 RiskIndex 최대 60개를 위험도 추이에 사용한다.

`DeviceCard.tsx`는 다음을 표시한다.

- 장치 ID와 상태
- RiskIndex
- 심박과 피부온도
- 팬 출력과 냉각 단계
- 가장 큰 위험 기여 원인
- 센서 오류
- GSR, 환경온도·습도, Finger, LoRa RSSI, GPS 위치

`TacticalMap.tsx`는 `raw.gps_fix == true`이고 위도·경도가 유한한 장치만 지도에 표시한다.

---

## 14. 서버와 대시보드 실행

다음 명령은 Windows PowerShell 기준이다.

### 14.1 저장소 준비

```powershell
git clone https://github.com/yeoniix/heatsentry-tac.git
Set-Location heatsentry-tac
py -m venv .venv
.\.venv\Scripts\Activate.ps1
pip install -r server\requirements.txt
```

### 14.2 개발 모드 서버

```powershell
uvicorn heatsentry.server.main:app --reload --port 8000
```

브라우저에서 `http://127.0.0.1:8000/`을 열어 다음과 비슷한 응답을 확인한다.

```json
{"message":"HeatSentry gateway (schema_version 2.0) is running","time":"..."}
```

### 14.3 장치 키를 사용하는 서버

```powershell
$env:HEATSENTRY_DEVICE_KEYS='{"HS-W-001":"충분히-긴-임의-비밀키"}'
$env:HEATSENTRY_CORS_ORIGINS='http://127.0.0.1:5173,http://localhost:5173'
uvicorn heatsentry.server.main:app --host 0.0.0.0 --port 8000
```

브리지의 `X-HS-Device-Key`도 같은 키여야 한다. 키와 지도 API 키는 Git에 커밋하지 않는다.

### 14.4 대시보드

```powershell
Set-Location dashboard
npm install
Copy-Item .env.example .env.local
npm run dev
```

기본 주소는 `http://localhost:5173`이다. 게이트웨이가 다른 PC에 있으면 `.env.local`에 다음을
추가한다.

```dotenv
VITE_GATEWAY_URL=http://게이트웨이_IP:8000
VITE_KAKAO_MAP_APP_KEY=카카오_JavaScript_키
```

카카오 Developers의 Web 플랫폼에도 `http://localhost:5173`과 실제 운영 도메인을 등록해야 한다.
지도 키가 없어도 장치 카드와 나머지 대시보드는 작동하고, 지도 영역에는 설정 안내가 나온다.

### 14.5 실행 순서

1. FastAPI 게이트웨이 실행
2. LoRa 베이스 수신기 연결
3. LoRa→HTTP 브리지 실행
4. React 대시보드 실행
5. 벨트 전원 ON
6. 손목 전원 ON 및 착용
7. 시리얼과 대시보드에서 sequence가 증가하는지 확인

---

## 15. 펌웨어 업로드와 확인 절차

### 15.1 손목

1. `display_protocol.h`를 `.ino`와 같은 Arduino 스케치 폴더에 둔다.
2. 보드 `ESP32 Dev Module`, 올바른 COM 포트를 선택한다.
3. 업로드 속도가 921600에서 불안정하면 460800 또는 115200으로 낮춘다.
4. 업로드 후 시리얼 모니터를 115200으로 연다.
5. 다음 로그를 확인한다.

```text
Calibrating GSR... keep still.
System ready
GSR baseline = ...
Finger=..., IR=..., BPM=..., Avg BPM=..., Temp=..., GSR=..., GSRdiff=..., Alert=...
```

`Hash of data verified`와 `Hard resetting via RTS pin`은 업로드 성공이다.

### 15.2 벨트

1. 실제 Heltec 보드 모델을 선택한다.
2. DHT11 DATA가 GPIO33인지 다시 확인한다.
3. 손목 MAC이 `gloveMac[]`와 같은지 확인한다.
4. 시리얼 모니터 115200에서 다음 초기화 로그를 확인한다.

```text
[OK] MCU
[OK] BUTTON GPIO7
[OK] FAN1 GPIO6
[OK] FAN2 GPIO47
[OK] DHT11 GPIO33
[OK] GPS UART
[OK] GLOVE PEER
[OK] ESP-NOW
[OK] LoRa TX
Telemetry Size : 35 bytes
Display Size   : 12 bytes
SYSTEM READY
```

### 15.3 정상 데이터 흐름

벨트 시리얼에서 다음을 순서대로 확인한다.

```text
[ GLOVE / ESP32U ]
BPM          : ...
Skin Temp    : ...
Finger       : YES
ESP-NOW age  : 0~수천 ms

[ DHT11 ]
Air Temp     : ...
Humidity     : ...

[ GPS ]
GPS chars    : 계속 증가
Fix          : YES

LoRa bytes   : 35
>>> LoRa TX DONE <<<
```

---

## 16. 단계별 통합 시험

한 번에 전체를 켜기보다 아래 순서로 시험하면 고장 위치를 빠르게 찾을 수 있다.

### 시험 A — 손목 센서 단독

- 손가락을 올리면 `Finger=YES`, IR > 50000
- 몇 초 후 `Avg BPM`이 45~180 범위
- TMP117 온도가 출력
- GSR과 GSRdiff가 출력

### 시험 B — 손목 OLED 단독

- I2C 스캐너에서 `0x3C`, `0x48`, `0x57` 확인
- 부팅 시 `HEATSENTRY / STARTING`
- 벨트가 없으면 3초 이후 `LINK LOST`

### 시험 C — ESP-NOW 왕복

- 벨트에서 `NO DATA`가 아닌 손목 센서값 출력
- 손목 OLED에서 `SENSOR CHECK`, `BASELINE`, `NORMAL` 순서 확인
- 벨트 전원을 끄면 3초 이내 손목에 `LINK LOST`

### 시험 D — 팬

- 시험용으로 피부온도 임계값을 안전하게 시뮬레이션하거나 코드의 테스트 상수를 임시 사용
- 29°C 이상 30°C 미만에서 `WARNING`, 팬 OFF
- 30°C 이상에서 `DANGER`, 팬 두 개 ON
- 테스트 후 임계값을 원래 값으로 복구

### 시험 E — DHT11 노이즈

- 팬 OFF에서 연속 DHT 성공
- 팬 ON에서도 캐패시터 적용 후 대부분 성공
- 실패 시 `[DHT11] retry` 후 회복하는지 확인
- 팬 ON 때만 계속 실패하면 전원·배선 분리와 드라이버 억제를 보강

### 시험 F — GPS

- `GPS chars`가 증가하면 UART 배선 정상
- 야외에서 위성 수와 위치 Fix 확인
- Fix 후 flags bit2, 즉 `0x04`가 포함되는지 확인

### 시험 G — LoRa

- 벨트 `LoRa bytes : 35`
- 벨트 `LoRa TX DONE`
- 베이스 수신 길이 35
- payload 시작 `5A A5 01 01`
- RSSI/SNR 기록

### 시험 H — 서버·대시보드

- 브리지 POST 응답 `status: ok`
- `/api/v2/devices`에 `HS-W-001` 생성
- 대시보드 카드의 seq가 증가
- GPS Fix 후 지도 마커 표시
- WebSocket을 끊어도 1.5초 REST 폴링으로 갱신

---

## 17. 문제 해결표

| 증상 | 가능한 원인 | 확인/해결 |
| --- | --- | --- |
| 손목 시리얼이 완전히 비어 있음 | 잘못된 COM 포트, baud, 업로드 실패, 전원 문제 | COM 확인, 115200, 리셋 버튼, USB 데이터 케이블 확인 |
| 업로드 중 `Unable to verify flash chip connection` | 921600 업로드 불안정, USB 케이블/허브, 전원 노이즈 | 업로드 속도 낮춤, 허브 제거, 센서/모터 전원 분리 후 업로드 |
| 벨트 `NO DATA` | 손목 MAC 불일치, ESP-NOW 채널, 손목 미부팅 | STA MAC 재확인, 양쪽 채널 통일, 손목 로그 확인 |
| 벨트 `SIZE ERROR` | SensorPacket 선언/정렬 불일치 | 양쪽 선언 비교, `sizeof` 28 확인 |
| 손목 OLED `LINK LOST` | 벨트 송신 실패, peer MAC 불일치, 3초 timeout | 벨트 `[DISPLAY] SEND ERROR`, MAC, 전원 확인 |
| OLED가 검은 화면 | 주소가 0x3C 아님, SDA/SCL 반대, 전원 문제 | I2C 스캐너, 주소 변경, GPIO21/22 확인 |
| MAX30102/TMP117 init failed | I2C 배선/전원/주소 문제 | 센서 하나씩 연결, I2C 스캔, 풀업 확인 |
| 심박 0 | 손가락 없음, IR < 50000, 움직임, 광학 접촉 불량 | IR 로그 확인, 밀착, LED 세기/임계값 조정 |
| DHT11 READ FAILED | 모터 노이즈, 전원 강하, 배선, 손상 | GPIO33, 100uF+0.1uF, 전원 분리, 센서 교체 |
| GPS chars 0 | GPS TX와 GPIO38 미연결, baud/전원 문제 | TX→RX 교차 배선, 9600bps 확인 |
| GPS chars 증가하지만 NO FIX | 실내, 안테나 간섭, 콜드 스타트 | 야외 이동, 안테나 이격, 충분히 대기 |
| `LoRa TX DONE`인데 베이스 무수신 | 주파수/SF/BW/CR/IQ 불일치, 안테나 | 표 11.1 전체 대조, 안테나 연결 |
| 서버 POST 422 | TelemetryV2 필드/범위/상태 불일치 | 응답 body의 validation error 확인 |
| 서버 `duplicate_ignored` | sequence 중복/감소/16비트 wrap | 확장 sequence 구현 |
| 카드에는 뜨지만 지도 없음 | `gps_fix=false`, 좌표 null, Kakao 키/도메인 | JSON raw, `.env.local`, Kakao 플랫폼 확인 |
| DANGER를 POST하면 422 | 현재 서버 상태 enum에 DANGER 없음 | 스키마 확장 또는 COOLING으로 명시적 매핑 |
| RiskIndex가 `—` | 35B 패킷에 RiskIndex 없음, 값 255 | 전체 알고리즘 포팅 또는 v2 패킷 확장 |

---

## 18. 현재 구현의 제한과 다음 개선 순서

### 필수 통합 작업

1. 베이스 LoRa 수신기와 시리얼 출력 구현
2. 시리얼→35B 디코더→`POST /ingest/telemetry` 브리지 구현
3. 16비트 LoRa sequence wrap 처리
4. bit4 Emergency와 bit5 Fan을 Python enum에 추가
5. 실제 벨트 상태를 보낼지, 대시보드에서 축약 매핑할지 결정

### 정확도·기능 개선

1. GitHub의 전체 RiskIndex/FSM을 벨트에 포팅하거나 벨트용 경량판으로 명세
2. BPM·GSR·환경온도를 벨트 상태 계산에 반영
3. `COOLING`, `HIGH_RISK` 전이 조건 구현
4. 팬 PWM 50/100% 단계 구현
5. 팬 전류·회전 검출을 추가해 “명령”과 “실제 동작”을 구분
6. 배터리 전압/잔량 측정 추가

### 통신 신뢰성 개선

1. SensorPacket을 고정 폭 packed/versioned 형식으로 교체
2. ESP-NOW 채널 고정과 암호화
3. DisplayPacket 송신자 MAC 검증
4. LoRa 애플리케이션 수준 CRC 또는 메시지 인증 추가
5. 패킷 손실률, RSSI/SNR, 마지막 수신 age 관제 표시

### 안전 정책 정합성 개선

1. 현재 5초 자동 해제 비상 동작과 “현장 확인 전까지 래치” 정책 중 하나를 공식 결정
2. 팬 드라이버 고장·과전류·저전압 시 안전 상태 정의
3. 센서 데이터가 오래됐을 때 팬을 끄는 현재 정책이 요구사항에 맞는지 위험 분석
4. 대시보드 확인과 실제 장치 비상 해제를 계속 분리

---

## 19. 재현 완료 체크리스트

### 손목

- [ ] ESP32 Dev Module에 손목 코드 업로드
- [ ] I2C GPIO21/22 확인
- [ ] OLED `0x3C`, TMP117 `0x48`, MAX30102 `0x57` 확인
- [ ] GSR AO GPIO34 확인
- [ ] 진동 모터 구동회로 GPIO25 확인
- [ ] 손목 STA MAC 기록
- [ ] Finger, BPM, TMP117, GSR 시리얼 확인

### 벨트

- [ ] Heltec 보드 모델과 Arduino 보드 설정 일치
- [ ] `gloveMac[]`를 실제 손목 MAC으로 설정
- [ ] DHT11 DATA GPIO33
- [ ] DHT11 VCC-GND 100uF, 필요 시 0.1uF 병렬
- [ ] GPS TX→GPIO38, GPS RX←GPIO39, 9600bps
- [ ] 비상 버튼 GPIO7-GND
- [ ] 팬 드라이버 GPIO6/GPIO47, 공통 GND
- [ ] TelemetryPacket 35B, DisplayPacket 12B 확인

### 로컬 폐루프

- [ ] 손목→벨트 센서 1초 전송
- [ ] 벨트→손목 상태 0.5초 전송
- [ ] 3초 통신 손실 화면 확인
- [ ] 기준선 10초 후 NORMAL 확인
- [ ] WARNING/DANGER/EMERGENCY와 팬 확인
- [ ] 경고 진동 확인

### LoRa·관제

- [ ] 양쪽 LoRa 설정 일치
- [ ] 베이스에서 35B와 magic 수신
- [ ] RSSI/SNR 확보
- [ ] 브리지에서 flags 기반 null/유효값 처리
- [ ] sequence wrap 처리
- [ ] FastAPI `/ingest/telemetry` 응답 ok
- [ ] 장치 카드 실시간 갱신
- [ ] GPS Fix 후 지도 표시
- [ ] 실제 벨트 state 전달 방식 결정 및 문서/코드 동기화

---

## 20. 한 문장 요약

현재 HeatSentry 실물 시스템은 **손목이 생체센서를 측정해 ESP-NOW로 벨트에 보내고, 벨트가 상태와
팬을 결정해 손목 OLED로 되돌려 주며, 전체 원시 데이터를 35바이트 LoRa로 송신하는 로컬 폐루프**다.
대시보드까지 완전하게 연결하려면 **베이스 LoRa 수신·HTTP 브리지와 벨트 state/RiskIndex 전달
계약**을 마지막으로 확정해야 한다.

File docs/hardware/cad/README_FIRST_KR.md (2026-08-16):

# HeatSentry V7 TRUE FINAL

이 폴더는 V6에서 확인된 조립 불가/유로/서비스성 문제를 기준으로 형상을 다시 만든 **CAD-level 최종 출력 후보**입니다.
STEP은 Fusion 360에서 직접 불러올 수 있고, STL은 바로 슬라이서에서 사용할 수 있습니다. 전체 형상의 생성 소스는 `HeatSentry_V7_PARAMETRIC_SOURCE.py`입니다.

## 1. 고정 좌표와 외형

- X = 허리 좌우: 본체 240 mm
- Y = 몸에서 바깥 방향 깊이: 본체 72 mm
- Z = 위아래: 본체 90 mm
- 외부/팬 면 = Y 음(-) 방향
- 사람 등/서비스 커버 = Y 양(+) 방향
- 기본 벽 두께 = 2.4 mm
- 좌/우 셸 분할, 각각 독립적으로 220 mm급 프린터에서 출력 가능
- 상부 덕트 riser 높이 = 18 mm

## 2. V6에서 바뀐 핵심 구조

### 셸
- Left/Right shell 모두 **각각 단일 solid**로 다시 생성했습니다.
- 보스, 팬 포켓, 덕트 riser, 격벽, 채널 벽, 가이드가 모두 셸과 실제 Boolean Join되어 있습니다.
- 중앙 이음은 접착제만 의존하지 않습니다.
  - 4개 일체형 alignment tongue/pocket
  - `06_CENTER_BRIDGE_PLATE...` 2개
  - 후면 서비스 커버 10점 체결
  - 중앙 seam에는 얇은 실리콘/가스켓을 추가해 기밀을 잡습니다.

### 팬
- 40 x 40 x 10.3 mm 팬 기준
- 팬은 **외부에서 삽입/교체**합니다.
- 41 mm 정사각 포켓 + 32 x 32 mm M3 피치
- 팬 뒤 Ø37 유효 opening
- 팬 뒤쪽에서 격벽 전면까지 약 **20.55 mm plenum** 확보
- 그릴은 별도 부품이며 팬과 동일한 4개 M3 나사로 체결합니다.
- 그릴과 팬 사이에 44 x 44 mm 정도의 교체식 얇은 필터 폼/메시를 넣을 수 있습니다.

### 공기 유로
- 외부 -> FAN -> plenum -> 45도 turning vane -> 상부 capsule port -> riser -> duct
- 상부 opening은 **40 x 26 mm capsule 형상**입니다.
- 상부 opening 면적 약 894.9 mm²
- 팬 backer Ø37 opening 면적 약 1075.2 mm²
- 상부/팬 opening 면적비 약 **83.2%**로 V6의 Ø25.6 급축소를 제거했습니다.
- 왼쪽/오른쪽 팬은 각각 56 mm 폭의 독립 채널 안에서 동작합니다.
- 덕트와 전자부 사이의 separator는 별도 판이 아니라 셸에 일체형입니다.

### 전자부
- 일체형 separator 후면~rear inner wall 깊이 약 **33.9 mm**
- 140 x 70 x 15 mm power bank 기준 후면 여유 약 **10.2 mm**
- 30 x 55 x 25 mm ESP reference 기준 후면 여유 약 **5.4 mm**
- 배터리는 `04_BATTERY_CRADLE...` + Velcro strap 방식으로 탈착합니다.
- ESP는 `05_ESP_UNIVERSAL_SLED...`에 cable tie로 고정하므로 특정 PCB 나사홀 위치에 종속되지 않습니다.
- 팬 배선은 separator의 Ø8.2 mm 홀을 통과한 뒤 고무 grommet 또는 RTV로 밀봉합니다.
- 우측 하부에는 Ø8.5 mm 실제 관통 cable/grommet port 2개가 있습니다.

### 후면 서비스 커버
두 버전을 제공합니다.

1. `03_SERVICE_COVER_PCM_READY_V7`
   - PCM carrier 체결 보스 포함
2. `03B_SERVICE_COVER_FLAT_NO_PCM_V7`
   - PCM을 쓰지 않을 때 몸쪽이 완전히 평평한 버전

공통:
- 216 x 82 mm
- rear opening 204 x 74 mm
- 10개 M3 체결점
- 안쪽에 gasket groove 포함
- 216 x 82 mm 판은 45도로 회전하면 약 210.7 x 210.7 mm footprint라 220 x 220 mm급 베드에 들어갑니다. brim을 크게 쓰지 않는 것을 권장합니다.

### 벨트
- 셸을 관통하지 않는 별도 50 mm webbing loop 구조
- 좌/우 각 4개 M3 체결
- 벨트가 전자부/송풍부 벽을 뚫지 않습니다.

### PCM
- `10_PCM_CARRIER_UNIVERSAL_V7`
- nominal max reference: 약 160 x 64 x 8 mm
- 고정은 Velcro strap + 4개 M3
- PCM 실제 크기가 더 작으면 strap으로 조절 가능합니다.
- PCM을 사용하지 않으면 flat service cover를 사용하세요.

## 3. 덕트 어댑터

본체 riser 자체는 44 x 30 mm 외형의 capsule 형상입니다.

- `11_DUCT_ADAPTER_TO_32mm_OD_HOSE_V7`
  - 32 mm OD 호스를 끼우는 socket, nominal ID 32.4 mm
  - 기본 추천
- `12_DUCT_ADAPTER_TO_25mm_OD_HOSE_COMPAT_V7`
  - 25 mm OD 호스 호환용, nominal ID 25.4 mm
  - 유로 단면이 다시 작아지므로 **호환성용**입니다.

어댑터는 필요한 규격을 **2개 출력**합니다.

## 4. 출력 수량

필수:
- 01_LEFT_SHELL_V7 x1
- 02_RIGHT_SHELL_V7 x1
- 서비스 커버 둘 중 하나 x1
- 04_BATTERY_CRADLE_140x70_V7 x1
- 05_ESP_UNIVERSAL_SLED_V7 x1
- 06_CENTER_BRIDGE_PLATE_PRINT_2X_V7 x2
- 07_BELT_LOOP_LEFT_50mm_V7 x1
- 08_BELT_LOOP_RIGHT_50mm_V7 x1
- 09_FAN_FILTER_GRILLE_40mm_PRINT_2X_V7 x2
- 선택한 duct adapter x2

선택:
- 10_PCM_CARRIER_UNIVERSAL_V7 x1

## 5. 권장 출력 조건

PETG 권장
- nozzle 0.4 mm
- layer 0.20 mm
- perimeter/wall 4줄 이상
- top/bottom 5 layer 이상
- 일반 부품 infill 25~35%
- belt loop 50~60%
- center bridge 60% 이상
- fan grille 40% 이상

열 삽입 인서트 보스는 인서트 실제 외경에 따라 pilot hole을 0.1~0.3 mm 조정할 수 있습니다. 현재 M3 nominal pilot은 4.2 mm입니다.

## 6. 조립 순서

1. Left/Right shell의 M3 heat-set insert를 먼저 삽입합니다.
2. 오른쪽 tongue pocket에 왼쪽 alignment tongue를 끼워 두 shell을 맞춥니다.
3. 중앙 seam의 전자실 측 둘레와 외기 접촉 seam에 얇은 실리콘 gasket/RTV를 적용합니다.
4. rear opening을 통해 center bridge plate 2개를 상/하단에 설치합니다.
5. 팬 2개를 전면에서 넣고 필터 + fan grille을 M3로 체결합니다.
6. 팬 전선을 separator grommet hole로 넘긴 후 hole을 밀봉합니다.
7. battery cradle을 설치하고 power bank를 Velcro로 고정합니다.
8. ESP universal sled를 설치하고 PCB를 cable tie로 고정합니다.
9. 케이블을 하부 Ø8.5 port로 빼고 실제 사용 grommet/봉합제로 마감합니다.
10. 서비스 커버 gasket을 넣고 M3 10개를 대각선 순서로 조금씩 조입니다.
11. 좌/우 belt loop를 설치하고 50 mm webbing을 통과시킵니다.
12. PCM 사용 시 PCM-ready cover + carrier를 설치합니다.
13. 상부 duct adapter를 2개 끼운 후 호스를 연결합니다.

## 7. 최종 CAD 검증 결과

`V7_GEOMETRY_VALIDATION.txt` / `V7_VALIDATION_FINAL.json` 참조.

- 모든 출력 STL: connected component = 1
- 모든 출력 STL: watertight = True
- Left shell solids = 1
- Right shell solids = 1
- Left/Right shell 의도치 않은 체적 간섭 = 0 mm³
- shell vs service cover = 0 mm³
- shell vs fan reference = 0 mm³
- shell vs power bank reference = 0 mm³
- shell vs ESP reference = 0 mm³
- belt loops vs shells = 0 mm³
- battery/ESP mount vs reference body = 0 mm³

## 8. 중요한 현실 조건

이 V7은 **CAD 형상과 조립 논리 기준 최종본**입니다. 실제 구매한 팬/보조배터리/ESP/호스의 제조 공차는 출력 전에 한 번만 실측하세요.

또한 팬 흡기와 상부 송풍구가 외부에 열려 있으므로 **장치 전체를 IP67이라고 부를 수는 없습니다.** 이 설계의 목표는 송풍부와 전자부를 일체형 separator + gasketed cover로 분리하는 것입니다. 실제 방진/방수 등급은 완성품 누수/침수 시험 없이 보증할 수 없습니다.

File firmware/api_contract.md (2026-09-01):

# 펌웨어 인터페이스 계약 (ICD 요약)

> 기준 문서: HS-SIID-002 v2.0. 이 문서는 손목(SU-W)/허리(SU-B) 펌웨어를 실제로 작성할 때 참고할
> "계약" 요약본이다. 바이트 단위 정의의 1차 소스는 `common/packets.py`이며, 이 문서와 코드가
> 어긋나면 **코드가 아니라 이 문서를 고친다** (인터페이스는 먼저 동결하고 구현은 교체 가능하게
> 한다는 통합 원칙).

## 형상 기준선

| 항목 | 기준 | 이 저장소 위치 |
| --- | --- | --- |
| protocol_version | 2 | `common/PROTOCOL_VERSION`, `common/packets.py` |
| risk_config_version | 0.3.0 | `algorithm/risk_config.py`의 `RISK_CONFIG_VERSION` |
| gateway_schema | 2.0 | `common/GATEWAY_SCHEMA_VERSION`, `common/schema.py` |
| test_vector | TV-20260808-A | `firmware/simulator/scenarios.py` (결정적 재생, 난수 없음) |

## 인터페이스 목록

| IF | 송신→수신 | 방식(문서) | 지금 구현 |
| --- | --- | --- | --- |
| IF-01 | 손목 센서→RiskTask | 로컬 큐, 10~1000ms | `firmware/simulator/wrist_node.py`의 `WristNode.tick()` (1Hz) |
| IF-02 | 손목→허리 | BLE GATT, 명령 즉시 | `WristNode._send_cool_cmd()` → `BeltNode.handle_cmd()` |
| IF-03 | 허리→손목 | BLE Notify, 1s/이벤트 | `CoolAck` 반환값(동기 호출) |
| IF-04 | 노드→게이트웨이 | BLE GATT, 1s/이벤트 | `POST /ingest/telemetry`·`/ingest/event`·`/ingest/command_ack` |
| IF-05 | 게이트웨이→UI | WebSocket, ≤1s | `GET /ws/live` |
| IF-06 | UI→게이트웨이 | REST, 사용자 동작 | `/api/v2/*` |
| IF-07 | 게이트웨이→지휘소 | 선택 KR920/LAN | 범위 밖(P2) |

IF-01~04는 실제 BLE 스택이 없는 지금 단계에서 **HTTP/인프로세스 호출로 같은 계약을 흉내낸
것**이다. 펌웨어 담당자가 실제 nRF52840 BLE 스택으로 옮길 때는 아래 바이트 레이아웃만 그대로
GATT characteristic payload로 쓰면 된다.

## BLE 역할과 GATT 서비스

게이트웨이가 Central, 손목·허리가 Peripheral. 손목↔허리 직접 연결 우선, 동시 연결 수 초과 시
손목이 허리 상태를 게이트웨이에 릴레이한다.

| Characteristic | 방향 | 속성 | 길이 | 구현 |
| --- | --- | --- | --- | --- |
| HS_STATUS | W→G/B | Notify | 24B | `common.packets.HsStatus` |
| COOL_CMD | W→B | Write+ACK | 12B | `common.packets.CoolCmd` |
| COOL_ACK | B→W | Notify | 16B | `common.packets.CoolAck` |
| BELT_STATUS | B→W/G | Notify | 20B | `common.packets.BeltStatus` (초안, 아래 참고) |
| SOS_EVENT | W/B→G | Indicate | 24B | 미구현 — CR 필요 |
| CONFIG | G→W/B | Write | 가변 | `PUT /api/v2/config` (HMAC 서명, `server/app/routes_api_v2.py`) |

### 바이트 레이아웃

### 현재 Heltec LoRa 센서 텔레메트리 (35B)

하드웨어 팀의 현재 구현은 `TelemetryPacket` packed 구조체를 LoRa로 보낸다. ESP32는
little-endian이므로 서버/게이트웨이 디코더도 같은 순서(`<HBBHBhHhIhHiiBhHB`)를 쓴다.
디코더 구현은 `common/glove_packets.py`에 있다.

| flags bit | 의미 |
| --- | --- |
| 0 | 장갑 데이터 유효 |
| 1 | DHT11 데이터 유효 |
| 2 | GPS Fix 유효 |
| 3 | Finger 감지 |
| 4 | 벨트 비상 버튼 활성 |
| 5 | 벨트 팬 ON |

`Finger=NO`, `BPM=0`, 또는 장갑 데이터 무효는 위험점수 0이 아니라 LCD의
`SENSOR CHECK / WEAR GLOVE` 상태로 처리한다. 이 LoRa payload는 현장 하드웨어
중간 형식이며, 게이트웨이 API의 `TelemetryV2`와는 별개다.

현재 ESP32 패킷에는 HRV와 IMU 활동량이 없으므로 `algorithm/hardware_adapter.py`는
HR·피부온도 상승률·GSR 변화·온습도 환경열부하 4개 특징만 사용한다. 없는 두 특징은
0으로 넣지 않고 가중치에서 제외한 뒤 남은 0.75 가중치로 재정규화한다.

**공통 헤더 + HS_STATUS (24B)** — `common/packets.py`의 `HsStatus`:

```
0      protocol_version u8      = 2
1      msg_type         u8      0x01 status
2-3    payload_len      u16 LE
4-7    monotonic_ms     u32 LE
8-9    sequence         u16 LE
10     state            u8      DeviceState enum
11     risk_index       u8      0~100, 255=invalid
12     sensor_quality   u8      0~100
13     flags            u8      bit0 FALL, bit1 SOS, bit2 SENSOR_LIMITED, bit3 COOLING
14-21  payload(8B)      -       heart_rate_bpm(u8), skin_temp_x100(u16), eda_norm_x1000(u16),
                                 battery_percent(u8), reserved(u16)
22-23  crc16            u16 LE  CRC-16/CCITT-FALSE
```

**COOL_CMD (12B)** — `common.packets.CoolCmd`:

```
0      version    u8
1      level      u8   fan percent (0/50/100)
2-3    duration_s u16 LE
4-5    cmd_id     u16 LE
6-7    sequence   u16 LE
8      reason     u8   CoolReason enum (RISK_FSM/COMMANDER/TEST/SAFETY_STOP/EMERGENCY)
9      flags      u8   bit0 TEST_MODE, bit1 SOS
10-11  crc16      u16 LE
```

**COOL_ACK (16B)** — `common.packets.CoolAck`:

```
0-1    cmd_id           u16 LE
2-3    sequence         u16 LE
4      result           u8   AckResult enum (OK/REJECTED_SAFETY/IDEMPOTENT_REPEAT)
5      actual_pwm       u8
6-7    current_mA       u16 LE
8-9    belt_temp_centiC i16 LE
10-11  error_bits       u16 LE
12-13  reserved
14-15  crc16            u16 LE
```

**BELT_STATUS (20B, 초안)** — `common.packets.BeltStatus`. ICD 표4는 길이(20B)와 내용
("배터리·전압·온도·팬")만 정하고 바이트 배치는 정하지 않았다. 아래는 통합팀 CR 승인 전까지의
제안이며, 실제 펌웨어 구현 전에 CR로 고정해야 한다:

```
0      protocol_version u8
1-2    sequence         u16 LE
3-6    monotonic_ms     u32 LE
7      battery_percent  u8
8-9    voltage_mV       u16 LE
10-11  belt_temp_centiC i16 LE
12     fan_pwm_percent  u8
13-14  fan_rpm          u16 LE
15-16  current_mA       u16 LE
17     error_bits       u8   (허리 관련 오류만: E301=bit0, E302=bit1, E303=bit2)
18-19  crc16            u16 LE
```

**SOS_EVENT (24B)** — 아직 코드로 구현하지 않았다. ICD는 "원인·위치상태·seq"만 명시한다.
현재는 EMERGENCY 상태 전이가 `HS_STATUS`의 `flags` bit1(SOS)과 `state=EMERGENCY`로 이미
전달되므로 기능적으로는 대체되지만, Indicate 방식의 별도 긴급 채널이 필요하면 CR로 필드를
확정한 뒤 `common/packets.py`에 추가한다.

## 연결·재전송 정책

1. COOL_CMD는 `cmd_id`+`sequence`를 포함하고, 500ms 이내 ACK 없으면 최대 3회 재전송한다.
   구현: `firmware/simulator/wrist_node.py`의 `WristNode._send_cool_cmd()` (`RawTick.drop_ack_attempts`로
   시험 가능).
2. 동일 `cmd_id` 재수신 시 허리는 팬을 재시작하지 않고 현재 결과만 ACK한다(idempotent).
   구현: `firmware/simulator/belt_node.py`의 `BeltNode._processed_cmds` 캐시.
3. 상태 Notify는 손실 허용, Emergency는 Indicate 또는 애플리케이션 ACK을 쓴다.
4. 연결 손실 10초에서 COMMS_LOST(E201), 60초에서 팬 안전 타이머(50%로 하향) — 구현:
   `firmware/simulator/belt_node.py`의 `BeltNode.tick()`, 상수는 `common/errors.py`의
   `BLE_COMMS_LOST_S`/`FAN_SAFETY_TIMER_S`/`FAN_SAFETY_LEVEL`.

## 통합 오류코드

| 코드 | 조건 | 로컬 동작 | 관제 표시 | RiskIndex 영향 |
| --- | --- | --- | --- | --- |
| E101 | PPG Quality<70 10초 | HR 제외·SENSOR_LIMITED 가능 | 노란 품질 | HR_dev, HRV_suppression 제외 |
| E102 | EDA 접촉 손실 | EDA 가중치 제외 | 회색 입력 | EDA_delta 제외 |
| E103 | 피부온도 오류 | 온도 가중치 제외 | 센서 오류 | SkinTemp_slope 제외 |
| E104 | IMU 응답 없음 | 낙상 비활성·위험표시 | 기능 제한 | ActivityLoad 제외 |
| E105 | 환경 온습도 데이터 없음/저품질 | 환경열부하 제외 | 환경 센서 오류 | EnvHeatProxy 제외 |
| E201 | BLE 10초 손실 | 재연결·팬 안전타이머 | 통신 손실 | — |
| E301 | 팬 과전류/정지 | 팬 OFF | 긴급 장치오류 | — |
| E302 | 배터리 10% 이하 | 출력 제한 | 저배터리 | — |
| E303 | 접촉부 저온 | 팬 OFF·PCM 분리 안내 | 안전 알림 | — |
| E401 | 로그 저장 실패 | RAM 큐·재시도 | 무결성 경고 | — |

전체 정의: `common/errors.py`의 `ERROR_TABLE`.

## 저하 모드 원칙

1. `valid_weight >= 0.60`이면 가중치를 재정규화해 운용한다(`algorithm/risk_engine.py`).
2. IMU가 없으면 낙상 검출을 끄고 기능 제한을 표시한다(E104).
3. 게이트웨이가 없어도 손목↔허리 자동 냉각·로컬 경고는 유지된다 — `firmware/simulator/wrist_node.py`와
   `belt_node.py`는 게이트웨이 연결 여부와 무관하게 판정·안전 로직을 수행한다(전송만 별도).
4. 장거리 브리지(LoRa/KR920)가 없는 것은 전체 시스템 장애가 아니다 — IF-07은 애초에 P1 범위 밖.

## 호환성 규칙

- 수신 장치는 `protocol_version`과 `payload_len`을 먼저 확인한다(`common/packets.py`의
  `_check_common_header`).
- 알 수 없는 `msg_type`은 무시하고 `UNSUPPORTED_MESSAGE` 이벤트를 남긴다 — 현재
  `common/packets.py`는 알려진 타입만 디코드하며, 게이트웨이 쪽에서 알 수 없는 메시지를 받으면
  `PacketError`가 발생한다. 실제 펌웨어에서는 예외 대신 이벤트 로깅 후 무시하도록 구현해야 한다
  (P1 TODO).
- `protocol_version` 또는 `risk_config_version`이 오르면 CR에 반드시 명시한다
  (HS-SIID-002 "변경요청(CR) 필수 필드").

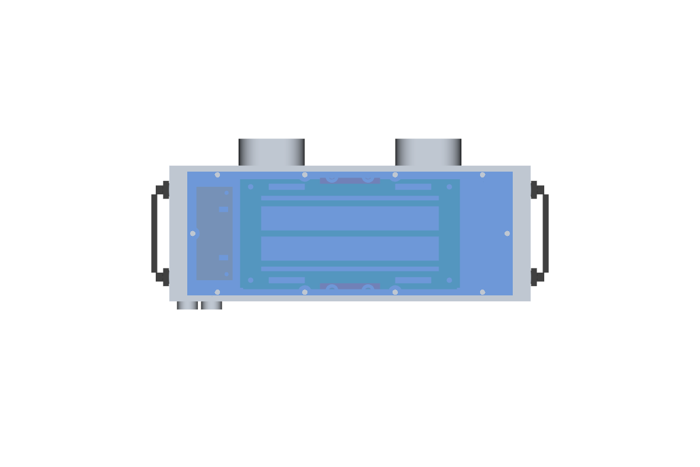
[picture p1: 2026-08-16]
docs/hardware/cad/V7_PREVIEW_REAR_INTERNAL.png

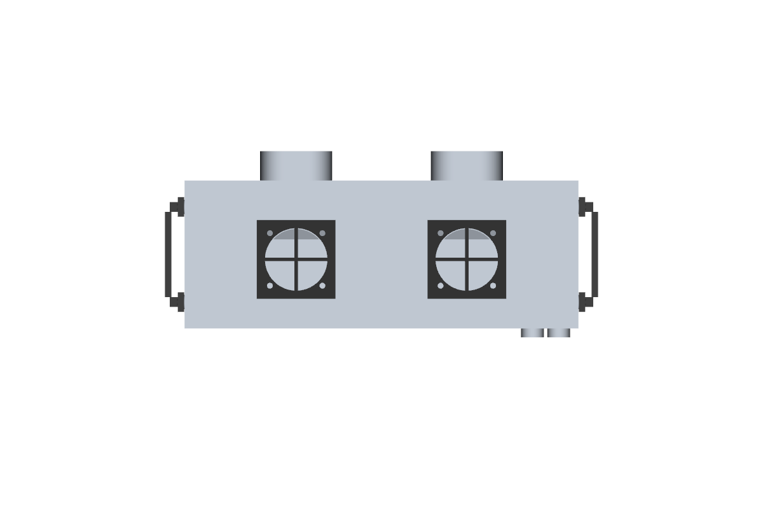
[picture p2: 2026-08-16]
docs/hardware/cad/V7_PREVIEW_FRONT.png

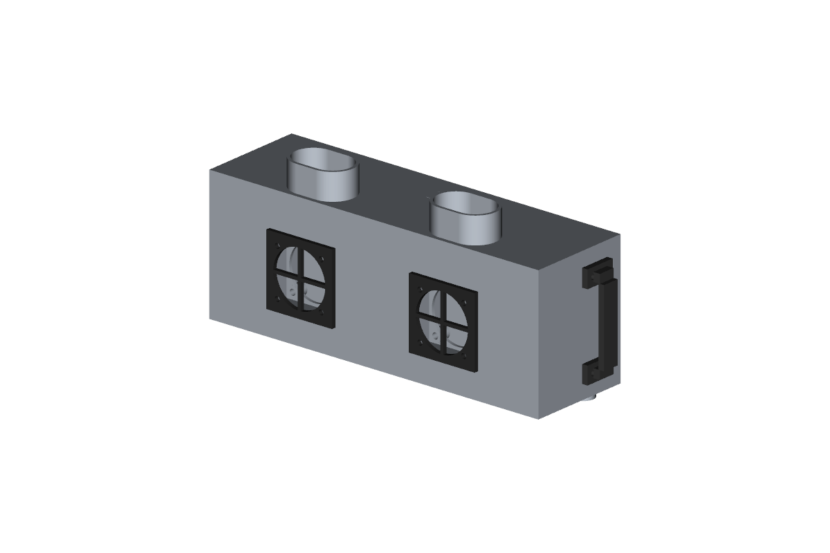
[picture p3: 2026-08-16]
docs/hardware/cad/V7_PREVIEW_ISO.png

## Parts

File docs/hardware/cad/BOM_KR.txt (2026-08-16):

HeatSentry V7 TRUE FINAL - BOM / 체결부

[기준 부품]
- 40 x 40 x 10.3 mm fan x2, 32 x 32 mm hole pitch
- Power bank 140 x 70 x 15 mm x1
- ESP/LoRa mounted envelope <= 30 x 55 x 25 mm x1
- 50 mm webbing belt
- 44 x 44 mm fan filter foam/mesh x2
- 선택: PCM pack <= 약 160 x 64 x 8 mm

[M3 heat-set insert - nominal 4.2 mm pilot]
- fan bosses: 8
- rear cover bosses: 10
- battery cradle bosses: 4
- belt-loop bosses: 8
- center bridge bosses: 4
- PCM-ready cover bosses: 4 (PCM 사용할 때)
- 합계: 34개 (PCM 미사용) / 38개 (PCM 사용)

[나사]
- fan grille + fan: M3 x 18~20, washer 포함, 8개
- rear service cover: M3 x 8, 10개
- battery cradle: M3 x 8, 4개
- belt loops: M3 x 8, 8개
- center bridge plates: M3 x 8, 4개
- PCM carrier: M3 x 8~10, 4개 (선택)
- ESP sled: M2.5 x 5~6 self-tapping 또는 실제 사용하는 체결 방식, 4개

[실링/배선]
- rear-cover gasket: 2 mm silicone cord 또는 얇은 closed-cell foam gasket
  rear opening 둘레 기준 약 556 mm이므로 0.65 m 이상 준비 권장
- center seam: 얇은 silicone gasket/RTV
- fan wire separator hole: Ø8.2 mm hole용 grommet 또는 RTV
- bottom cable ports: Ø8.5 mm hole에 맞는 grommet/밀봉 부품 x2

[덕트]
- 32 mm OD hose 사용: 11_DUCT_ADAPTER... x2
- 25 mm OD hose 사용: 12_DUCT_ADAPTER... x2 (airflow 제한이 더 큼)

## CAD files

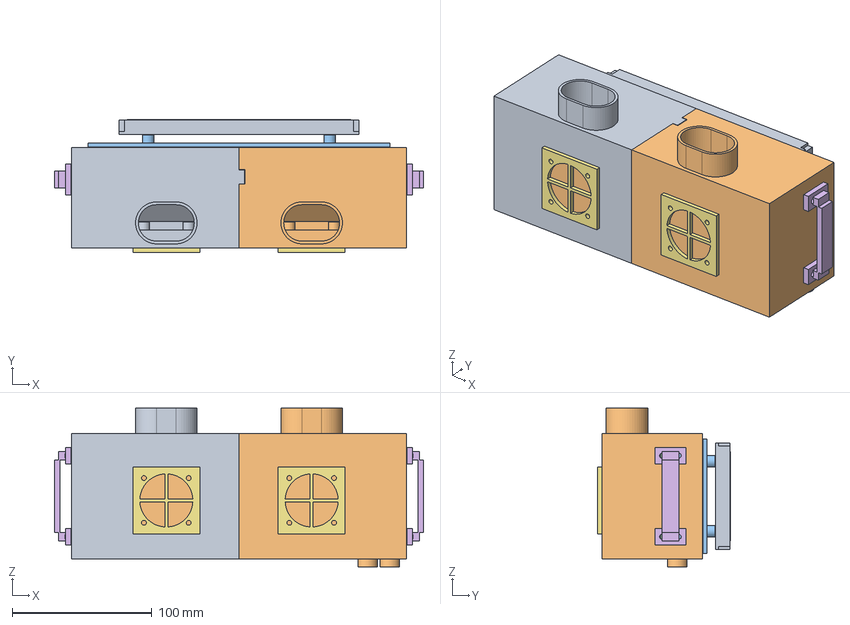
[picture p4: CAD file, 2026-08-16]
docs/hardware/cad/HeatSentry_V7_TRUE_FINAL_ASSEMBLY.step
264.0 x 94.8 x 113.5 mm
LeftShell
RightShell
ServiceCover
BatteryCradle
ESPSled
BeltLoopL
BeltLoopR
FanGrilleL
FanGrilleR
CenterBridge1 x 2
PCMCarrier
REF_FAN_LEFT_40x40x10p3
REF_FAN_RIGHT_40x40x10p3
REF_POWERBANK_140x70x15
REF_ESP_30x55x25
REF_PCM_160x64x8

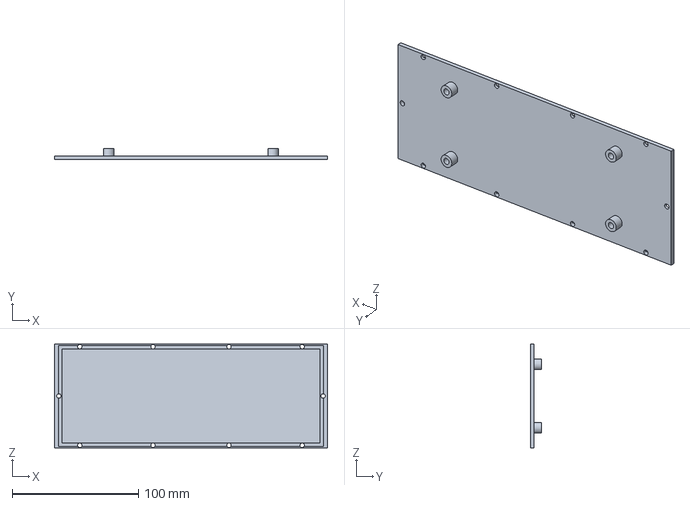
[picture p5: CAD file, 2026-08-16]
docs/hardware/cad/03_SERVICE_COVER_PCM_READY_V7.step
216.0 x 8.80 x 82.0 mm

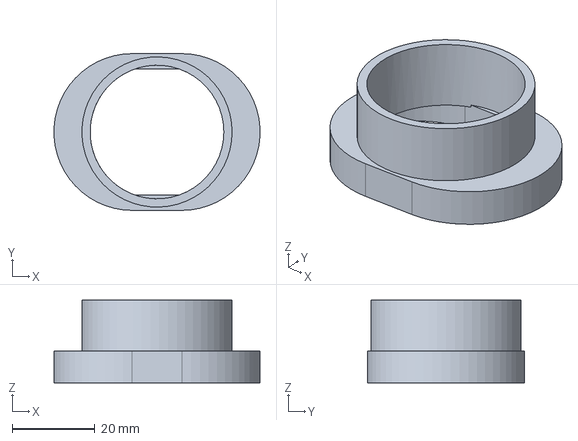
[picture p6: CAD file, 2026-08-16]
docs/hardware/cad/11_DUCT_ADAPTER_TO_32mm_OD_HOSE_V7.step
49.9 x 38.0 x 20.0 mm

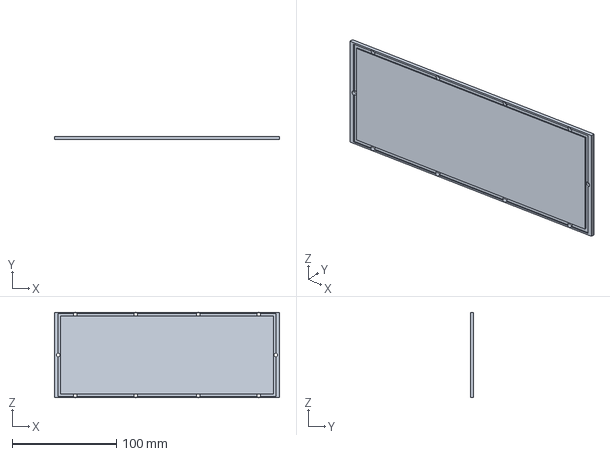
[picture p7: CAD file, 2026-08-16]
docs/hardware/cad/03B_SERVICE_COVER_FLAT_NO_PCM_V7.step
216.0 x 2.80 x 82.0 mm

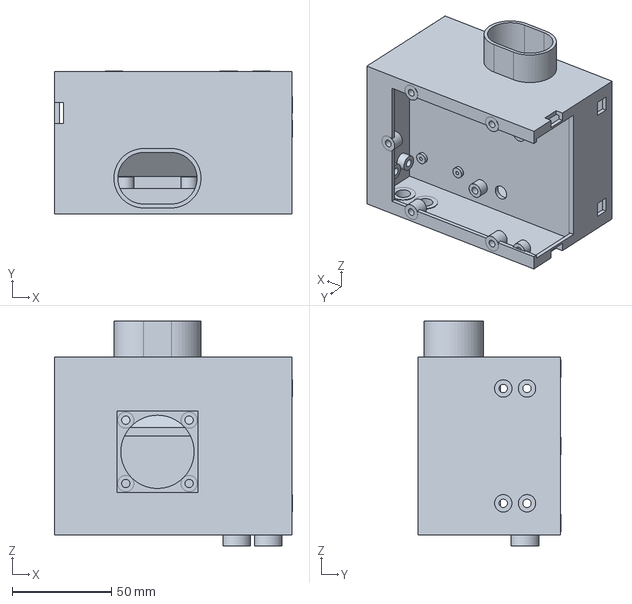
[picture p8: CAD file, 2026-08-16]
docs/hardware/cad/02_RIGHT_SHELL_V7.step
120.2 x 72.1 x 113.5 mm

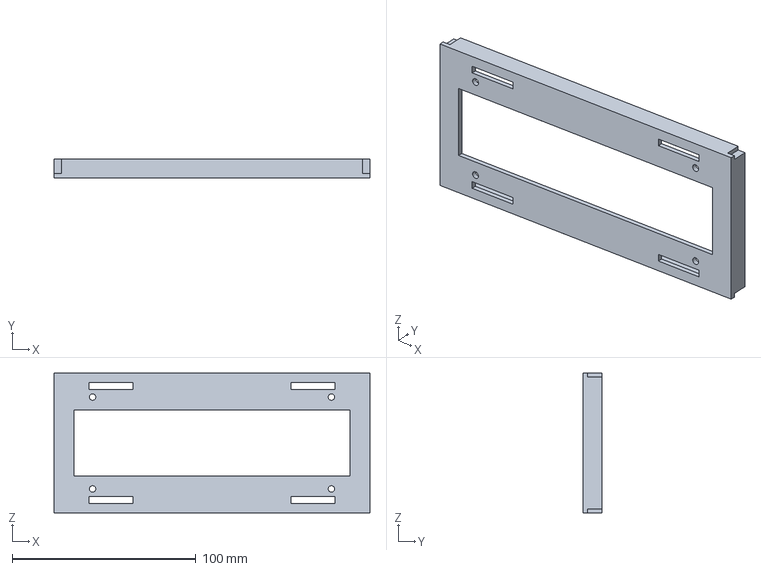
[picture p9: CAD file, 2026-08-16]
docs/hardware/cad/10_PCM_CARRIER_UNIVERSAL_V7.step
172.0 x 10.4 x 76.0 mm

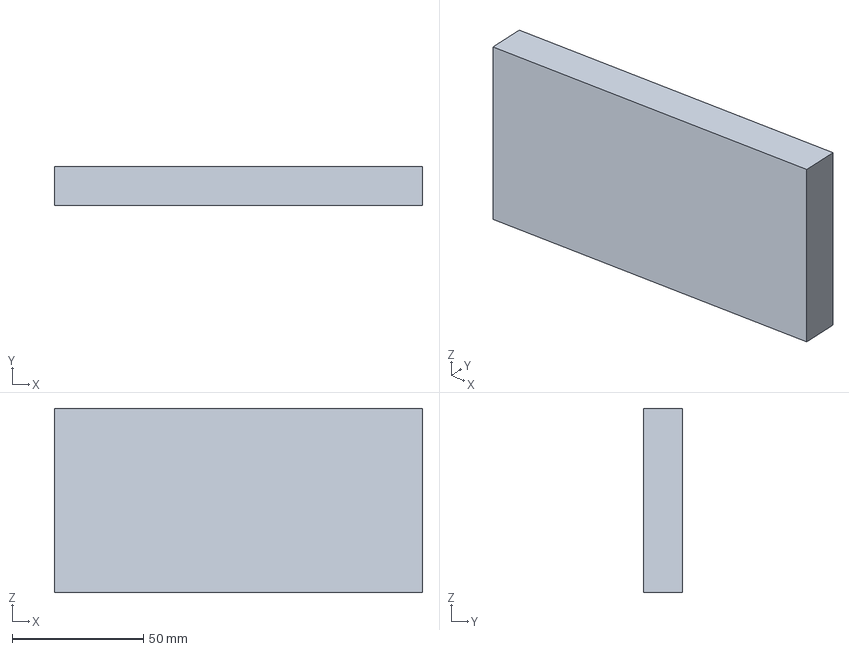
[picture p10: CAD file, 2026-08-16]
docs/hardware/cad/REF_POWERBANK_140x70x15.step
140.0 x 15.0 x 70.0 mm

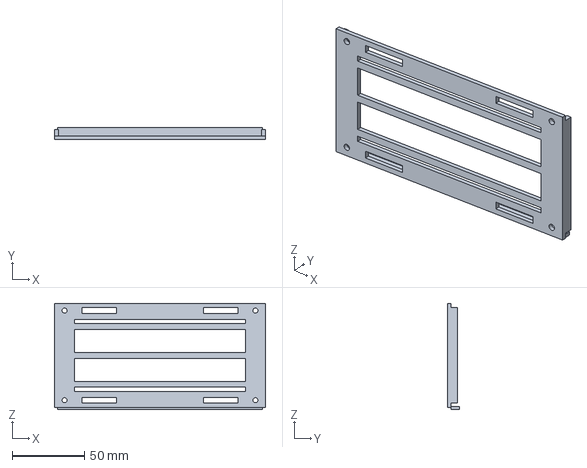
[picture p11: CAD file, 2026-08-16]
docs/hardware/cad/04_BATTERY_CRADLE_140x70_V7.step
146.0 x 8.40 x 73.5 mm

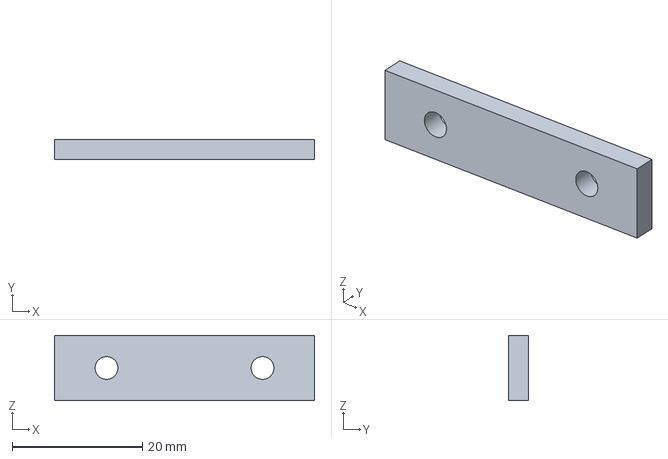
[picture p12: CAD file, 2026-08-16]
docs/hardware/cad/06_CENTER_BRIDGE_PLATE_PRINT_2X_V7.step
40.0 x 3.00 x 10.0 mm

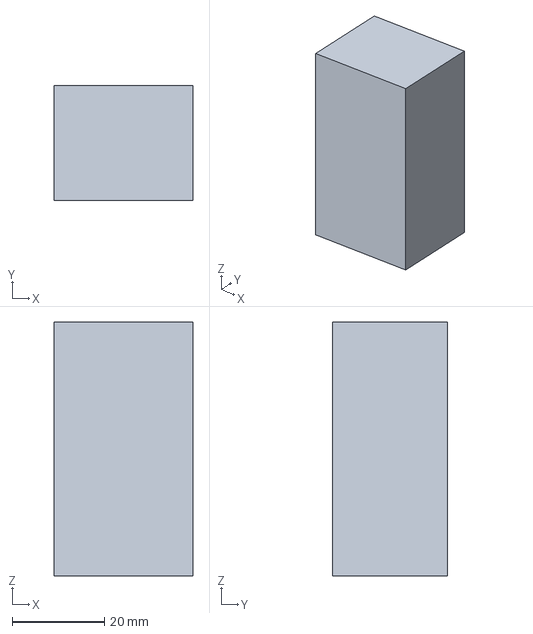
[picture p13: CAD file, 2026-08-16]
docs/hardware/cad/REF_ESP_30x55x25.step
30.0 x 25.0 x 55.0 mm

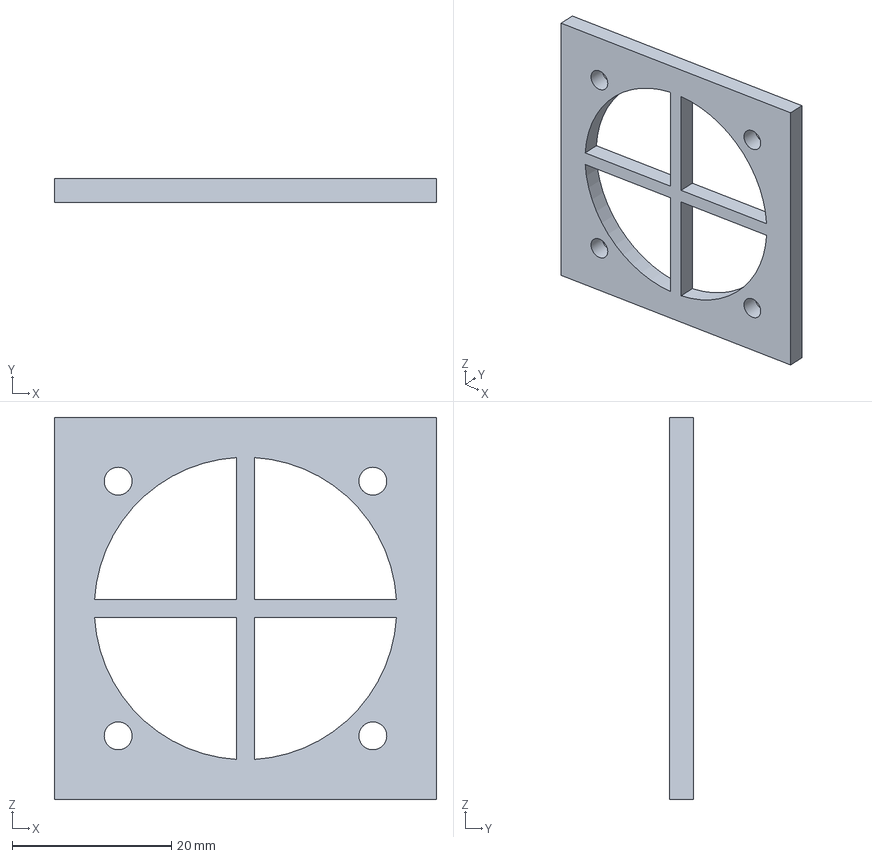
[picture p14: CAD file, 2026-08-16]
docs/hardware/cad/09_FAN_FILTER_GRILLE_40mm_PRINT_2X_V7.step
48.0 x 3.00 x 48.0 mm

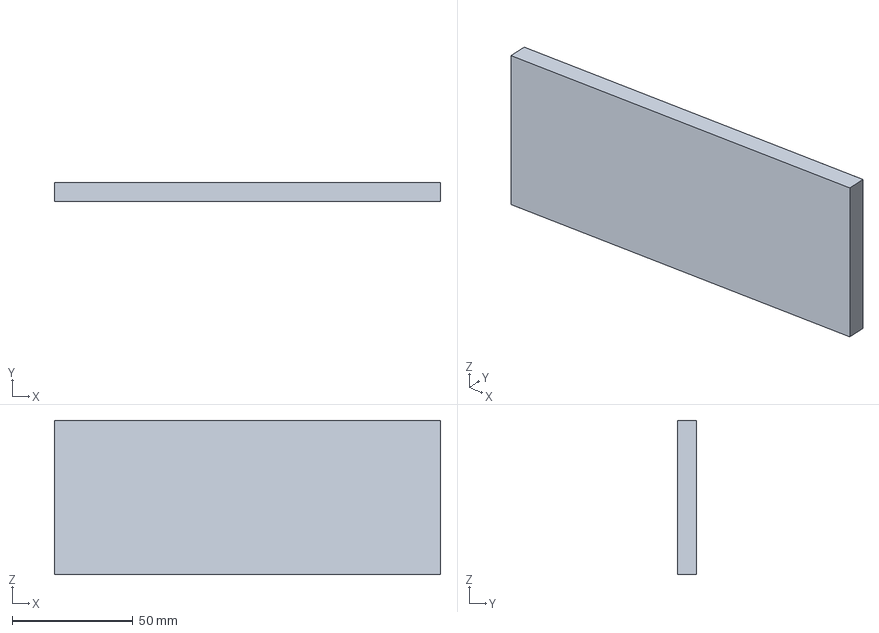
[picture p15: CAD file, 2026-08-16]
docs/hardware/cad/REF_PCM_160x64x8.step
160.0 x 8.00 x 64.0 mm

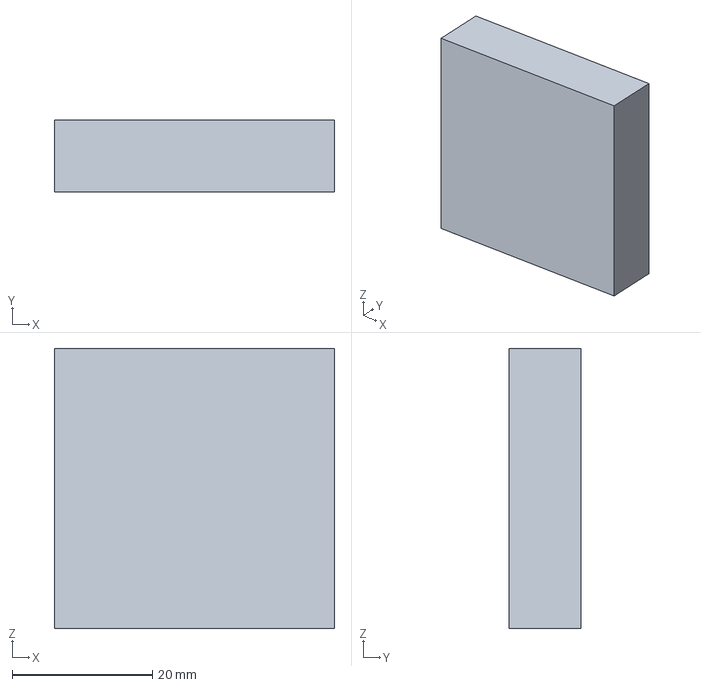
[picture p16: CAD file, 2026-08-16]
docs/hardware/cad/REF_FAN_RIGHT_40x40x10p3.step
40.0 x 10.3 x 40.0 mm

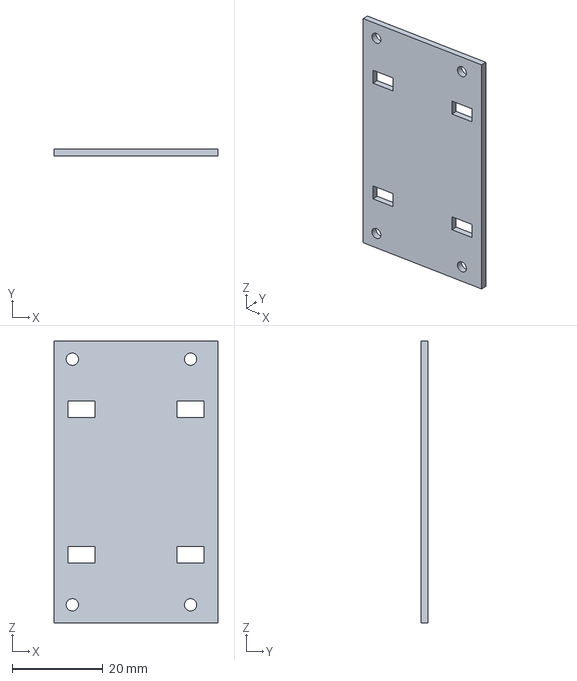
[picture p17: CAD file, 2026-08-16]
docs/hardware/cad/05_ESP_UNIVERSAL_SLED_V7.step
36.0 x 1.60 x 62.0 mm

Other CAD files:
docs/hardware/cad/01_LEFT_SHELL_V7.step
docs/hardware/cad/12_DUCT_ADAPTER_TO_25mm_OD_HOSE_COMPAT_V7.step
docs/hardware/cad/HeatSentry_V7_TRUE_FINAL_EXPLODED.step
docs/hardware/cad/07_BELT_LOOP_LEFT_50mm_V7.step
docs/hardware/cad/01_LEFT_SHELL_V7.stl
docs/hardware/cad/02_RIGHT_SHELL_V7.stl
docs/hardware/cad/03B_SERVICE_COVER_FLAT_NO_PCM_V7.stl
docs/hardware/cad/03_SERVICE_COVER_PCM_READY_V7.stl
docs/hardware/cad/04_BATTERY_CRADLE_140x70_V7.stl
docs/hardware/cad/05_ESP_UNIVERSAL_SLED_V7.stl
docs/hardware/cad/06_CENTER_BRIDGE_PLATE_PRINT_2X_V7.stl
docs/hardware/cad/07_BELT_LOOP_LEFT_50mm_V7.stl
docs/hardware/cad/08_BELT_LOOP_RIGHT_50mm_V7.step
docs/hardware/cad/08_BELT_LOOP_RIGHT_50mm_V7.stl
docs/hardware/cad/09_FAN_FILTER_GRILLE_40mm_PRINT_2X_V7.stl
docs/hardware/cad/10_PCM_CARRIER_UNIVERSAL_V7.stl
docs/hardware/cad/11_DUCT_ADAPTER_TO_32mm_OD_HOSE_V7.stl
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

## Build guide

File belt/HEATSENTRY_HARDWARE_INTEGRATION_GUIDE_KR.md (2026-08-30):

# HeatSentry 실물 하드웨어·통신·대시보드 통합 가이드

> 기준일: 2026-08-30  
> 소프트웨어 저장소: <https://github.com/yeoniix/heatsentry-tac>  
> 확인한 저장소 기준 커밋: `5dc9e50` (`feat: add GPS map to dashboard`)  
> 확인한 실물 펌웨어: `gloves_ESP32/gloves_ESP32.ino`, `gloves_ESP32/display_protocol.h`, `esplora_sen/esplora_sen.ino`

이 문서는 HeatSentry의 실물 손목 장치와 벨트 장치가 무엇을 측정하고, 어떻게 서로 통신하며,
벨트가 만든 데이터를 게이트웨이와 관제 대시보드까지 전달하는지를 재현 가능한 수준으로 설명한다.

HeatSentry는 의료 진단 장비가 아니다. 표시되는 심박, 피부온도, 환경값과 위험 상태는 현장 안전을
보조하기 위한 정보이며, 의식 저하·무응답·열질환 의심 증상이 있으면 장치 상태와 관계없이 현장
응급 절차를 우선해야 한다.

문서 작성에 사용한 최종 로컬 파일의 SHA-256은 다음과 같다. 이후 코드가 바뀌었는지 판단할 때 이
값과 비교할 수 있다.

| 파일 | SHA-256 |
| --- | --- |
| `gloves_ESP32.ino` | `437461259AECBA061A72F6E6CFEF52A70EAAD10C1633B41B96C7D7FB89A8D724` |
| `display_protocol.h` | `A1D9E8AB7BEECF084C23CE42059D87059CD24C51C56F21A4AC380A4DD90F9C4C` |
| `esplora_sen.ino` | `69452A081011E0B85B8E0B8BC0BC1AA6AE87151DD0DEA38D6D0E974C9B4C9C0A` |

---

## 1. 현재 구현 범위부터 정확히 이해하기

### 1.1 실물 하드웨어에서 구현된 기능

- 손목 ESP32가 MAX30102, TMP117, GSR 센서를 읽는다.
- 손목 ESP32가 센서값을 1초마다 ESP-NOW 브로드캐스트로 벨트에 보낸다.
- 벨트 ESP32가 손목 데이터, DHT11 환경 데이터, GPS 데이터, 비상 버튼을 한곳에 모은다.
- 상태 판단은 손목이 아니라 벨트에서 수행한다.
- 벨트가 상태를 0.5초마다 손목으로 다시 보내고, 손목 OLED가 그 결과만 표시한다.
- 손목은 경고 상태를 받으면 진동한다.
- 벨트는 피부온도 또는 비상 상태에 따라 팬을 켜거나 끈다.
- 벨트는 손목·DHT11·GPS·팬·비상 정보를 35바이트 LoRa 패킷으로 2초마다 송신한다.

### 1.2 GitHub 저장소에서 구현된 기능

- Python 기반 RiskIndex/FSM 알고리즘과 결정적 시뮬레이터
- FastAPI 게이트웨이의 `/ingest/*`, `/api/v2/*`, `/ws/live`
- SQLite 텔레메트리·이벤트 저장 및 이벤트 해시체인
- React/Vite 실시간 관제 대시보드
- 장치 상태 카드, 위험도 추이, 경보 확인, 응급 확인 기록, GPS 카카오맵
- 실물 벨트의 35바이트 LoRa 패킷을 푸는 Python 디코더 `common/glove_packets.py`

### 1.3 아직 자동으로 연결되지 않은 부분

현재 저장소에는 **LoRa 전파를 실제로 수신하여 35바이트를 Python에 넘기는 베이스 수신기/시리얼
브리지 프로그램이 없다.** 따라서 벨트의 `LoRa TX DONE`만으로 대시보드에 자동 표시되는 것은 아니다.

또한 현재 35바이트 LoRa 패킷에는 센서값과 플래그만 있고 다음 값이 없다.

- 벨트가 판정한 `state`
- 판정 원인 `cause`
- 정확한 `fanPercent`
- `risk_index`

따라서 현재 패킷만으로는 대시보드가 벨트의 `WARNING`, `DANGER`, `HIGH_RISK`를 완전히 구분할 수
없다. 이 문서의 12장에서 다음 두 연결 방법을 설명한다.

1. 펌웨어를 바꾸지 않고 35바이트를 사용하여 원시 센서·GPS와 제한된 상태를 표시하는 방법
2. 벨트를 상태 판단의 유일한 기준으로 유지하기 위해 LoRa 패킷에 상태 필드를 추가하는 권장 방법

저장소의 기존 기준 문서는 시뮬레이터 기준으로 손목 노드가 RiskIndex/FSM을 계산하고 BLE 또는
HTTP 등가 경로를 사용한다고 설명한다. 실물 최종 설계는 벨트가 상태를 계산하고 ESP-NOW+LoRa를
사용하므로 `README.md`, `docs/architecture.md`, `firmware/api_contract.md`도 이 문서와 함께 갱신해야
역할 설명이 충돌하지 않는다.

---

## 2. 전체 시스템 구조

```mermaid
flowchart LR
    subgraph W[손목 ESP32]
        MAX[MAX30102\nIR/심박]
        TMP[TMP117\n피부온도]
        GSR[GSR\n피부전도]
        OLED[SSD1306 OLED\n128x64]
        VIB[진동 모터]
    end

    subgraph B[벨트 Heltec ESP32-S3 + LoRa]
        FSM[상태 판정 FSM]
        DHT[DHT11\n환경온도/습도]
        GPS[ATGM336H\nGPS]
        BTN[비상 버튼]
        FAN[팬 드라이버/팬]
        LTX[LoRa 송신]
    end

    subgraph G[베이스·게이트웨이]
        LRX[LoRa 수신기\n현재 추가 필요]
        BRIDGE[35B 디코더·JSON 변환\n현재 추가 필요]
        API[FastAPI 게이트웨이]
        DB[(SQLite)]
    end

    subgraph D[관제 대시보드]
        CARD[장치 상태 카드]
        TREND[위험도 추이]
        MAP[GPS 카카오맵]
        EVENT[이벤트/확인 기록]
    end

    MAX --> WTX[SensorPacket 생성]
    TMP --> WTX
    GSR --> WTX
    WTX -- "ESP-NOW 1초 / 28B" --> FSM
    DHT --> FSM
    GPS --> FSM
    BTN --> FSM
    FSM --> FAN
    FSM -- "ESP-NOW 0.5초 / DisplayPacket 12B" --> OLED
    FSM --> VIB
    FSM --> LTX
    LTX -- "LoRa 922.3MHz 2초 / 35B" --> LRX
    LRX --> BRIDGE
    BRIDGE -- "HTTP POST /ingest/telemetry" --> API
    API --> DB
    API -- "WebSocket /ws/live" --> CARD
    API --> TREND
    API --> MAP
    API --> EVENT
```

핵심 원칙은 다음과 같다.

- 센서 취득은 손목과 벨트에서 나누어 수행한다.
- 착용자에게 즉시 필요한 상태 판단과 팬 제어는 벨트에서 수행한다.
- 손목 OLED는 자체 판단을 하지 않고 벨트가 보낸 상태를 표시한다.
- 서버와 대시보드가 끊겨도 손목↔벨트 로컬 폐루프는 계속 작동한다.
- 대시보드는 수신·저장·표시·확인 기록을 담당하며, 현장 팬을 직접 제어하지 않는다.

---

## 3. 권장 저장소 배치

실물 코드를 GitHub 저장소에 올릴 때는 역할이 바로 보이도록 다음 구조를 권장한다.

```text
heatsentry-tac/
├─ firmware/
│  ├─ glove_esp32/
│  │  ├─ glove_esp32.ino
│  │  └─ display_protocol.h
│  ├─ belt_heltec/
│  │  └─ belt_heltec.ino
│  └─ api_contract.md
├─ common/
│  └─ glove_packets.py
├─ server/
├─ dashboard/
├─ docs/
│  └─ hardware_integration_kr.md   # 이 문서
└─ README.md
```

Arduino IDE는 폴더명과 메인 `.ino` 파일명이 같을 때 다루기 편하다. 업로드 시에는 현재 파일을
다음과 같이 이름만 정리하면 된다.

| 현재 로컬 파일 | 저장소 권장 위치 |
| --- | --- |
| `gloves_ESP32/gloves_ESP32.ino` | `firmware/glove_esp32/glove_esp32.ino` |
| `gloves_ESP32/display_protocol.h` | `firmware/glove_esp32/display_protocol.h` |
| `esplora_sen/esplora_sen.ino` | `firmware/belt_heltec/belt_heltec.ino` |

`message.txt`는 화면 문구를 설계할 때 사용한 Python 초안이며 현재 ESP32 런타임에서 호출되지 않는다.
최종 OLED 문구의 기준은 `gloves_ESP32.ino`의 `updateDisplay()`다.

---

## 4. 하드웨어 구성

### 4.1 손목 장치

| 부품 | 역할 | 코드에서 사용하는 인터페이스 |
| --- | --- | --- |
| ESP32 Dev Module | 센서 취득, ESP-NOW, OLED, 진동 | Wi-Fi/ESP-NOW, I2C, ADC, GPIO |
| MAX30102 | IR 기반 손가락 감지 및 심박 계산 | I2C, 기본 주소 `0x57` |
| TMP117 | 피부 접촉 온도 | I2C, 일반적인 기본 주소 `0x48` |
| GSR 센서 | 피부전도 원시값 | ADC |
| SSD1306 OLED 128x64 I2C | 벨트가 계산한 상태 표시 | I2C, 주소 `0x3C` |
| 소형 진동 모터 + 구동회로 | 경고 촉각 알림 | GPIO 제어 |

### 4.2 벨트 장치

| 부품 | 역할 | 코드에서 사용하는 인터페이스 |
| --- | --- | --- |
| Heltec ESP32-S3 LoRa 계열 보드 | 상태 계산, 팬, GPS/DHT, ESP-NOW, LoRa | Wi-Fi/ESP-NOW, UART, GPIO, 내장 LoRa |
| DHT11 | 환경온도·습도 | 단일 DATA GPIO |
| ATGM336H | 위치, 고도, 속도, 위성 수 | UART 9600bps |
| 비상 버튼 | 수동 SOS | `INPUT_PULLUP` GPIO |
| 2채널 모터 드라이버 | 팬 전원 구동 | GPIO 두 개 |
| 냉각 팬 2개 | 착용자 냉각 | 모터 드라이버 출력 |

벨트 코드는 GPIO47을 사용하므로 일반 ESP32가 아니라 해당 핀이 있는 ESP32-S3 계열을 전제로 한다.
Heltec 보드 모델이 바뀌면 먼저 보드 핀맵과 `LoRaWan_APP.h` 지원 여부를 다시 확인해야 한다.

### 4.3 베이스 장치

대시보드까지 실물 데이터를 전달하려면 다음이 추가로 필요하다.

- 벨트와 같은 LoRa 설정을 사용하는 수신 보드
- 수신 보드와 게이트웨이 PC 또는 Raspberry Pi 사이의 USB 시리얼 연결
- 시리얼에서 받은 35바이트를 `TelemetryV2` JSON으로 변환하는 브리지 프로세스
- FastAPI 서버와 React 대시보드를 실행할 PC 또는 Raspberry Pi

---

## 5. 배선

### 5.1 손목 ESP32 배선

MAX30102, TMP117, SSD1306 OLED는 같은 I2C 버스를 공유한다.

| 장치 단자 | ESP32 핀 | 비고 |
| --- | ---: | --- |
| MAX30102 SDA | GPIO21 | I2C 공용 SDA |
| MAX30102 SCL | GPIO22 | I2C 공용 SCL |
| TMP117 SDA | GPIO21 | I2C 공용 SDA |
| TMP117 SCL | GPIO22 | I2C 공용 SCL |
| OLED SDA | GPIO21 | I2C 공용 SDA |
| OLED SCL | GPIO22 | I2C 공용 SCL |
| OLED VCC | 3.3V | 모듈 사양 확인 |
| OLED GND | GND | 모든 장치 공통 GND |
| GSR AO | GPIO34 | 12비트 ADC 입력, 0~4095 |
| 진동 모터 구동 입력 | GPIO25 | 모터를 GPIO에 직접 연결하지 말 것 |

전원은 사용 중인 센서 모듈 사양을 우선한다. ESP32 GPIO는 3.3V 로직이며 ADC 입력에 3.3V를 넘는
전압을 넣으면 안 된다. 진동 모터는 순간 전류와 역기전력이 있으므로 N-MOSFET 또는 트랜지스터,
보호 다이오드, 모터용 전원을 사용하고 ESP32와 GND를 공통으로 묶는다.

I2C 주소가 기본값일 때는 `0x57`, `0x48`, `0x3C`로 서로 충돌하지 않는다. 문제가 생기면 I2C
스캐너로 실제 주소를 먼저 확인한다. 여러 모듈의 풀업 저항이 병렬로 연결되어 전체 풀업 저항이 너무
낮아지지 않게 주의한다.

### 5.2 벨트 배선

| 장치 단자 | 벨트 GPIO/전원 | 비고 |
| --- | ---: | --- |
| DHT11 DATA | GPIO33 | 최종 변경 핀 |
| DHT11 VCC | 3.3V | 모듈 사양 확인 |
| DHT11 GND | GND | 공통 GND |
| GPS TX | GPIO38 | ESP32의 RX |
| GPS RX | GPIO39 | ESP32의 TX |
| GPS VCC | 3.3V | ATGM336H 모듈 사양 확인 |
| GPS GND | GND | 공통 GND |
| 비상 버튼 한쪽 | GPIO7 | `INPUT_PULLUP` |
| 비상 버튼 다른 쪽 | GND | 누르면 LOW |
| 드라이버 A-1A | GPIO6 | 팬 1 제어 |
| 드라이버 A-1B | GND | 현재 코드 배선 정의 |
| 드라이버 B-1A | GPIO47 | 팬 2 제어 |
| 드라이버 B-1B | GND | 현재 코드 배선 정의 |
| 모터 드라이버 VCC | 5V | 팬·드라이버 사양 확인 |
| 모터 드라이버 GND | 공통 GND | ESP32 GND와 반드시 공통 |

팬을 ESP32 GPIO에서 직접 구동하면 안 된다. 팬 전류는 모터 드라이버와 별도 전원에서 공급하고,
GPIO6/GPIO47은 제어 신호만 보낸다.

### 5.3 DHT11 노이즈 대책

확인된 증상은 팬 모터가 동작할 때 DHT11 읽기가 실패하는 것이었다. 현재 적용한 해결은 DHT11의
VCC와 GND 사이에 약 `100uF` 캐패시터를 추가하는 것이다.

```text
3.3V ----+---------- DHT11 VCC
         |
       + | 100uF 전해 캐패시터
         |
GND  ----+---------- DHT11 GND
```

- 전해 캐패시터의 `+`는 3.3V, `-`는 GND에 연결한다.
- 캐패시터는 DHT11 모듈 가까이에 둔다.
- 고주파 성분을 줄이기 위해 `0.1uF` 세라믹 캐패시터를 병렬로 추가하면 더 안정적이다.
- 팬 드라이버 전원에도 별도의 벌크 캐패시터를 두고 센서 전원선과 모터 전원선을 가능한 한 분리한다.
- 팬 배선은 센서 DATA/GPS 안테나와 떨어뜨리고, 모든 GND는 짧고 확실하게 공통화한다.
- 순간적인 Wi-Fi/ESP-NOW 간섭으로 DHT11이 가끔 실패할 수 있으므로 코드는 3회 재시도한다.

캐패시터는 전원 변동을 줄이는 대책이다. DHT11이 뜨거워지거나 탄 냄새가 나면 전원을 즉시 끄고
VCC/GND 역결선, 5V 오인가, 단락 여부를 확인한 뒤 센서를 교체해야 한다.

### 5.4 GPS 설치 대책

- GPS 안테나는 Heltec LoRa 안테나와 보드에서 가능하면 10cm 이상 이격한다.
- 최초 위치 고정은 실내보다 하늘이 열린 실외에서 시험한다.
- `GPS chars > 0`은 UART 문자가 들어온다는 뜻일 뿐 위치 고정 성공을 뜻하지 않는다.
- 위치가 유효하고 마지막 갱신 후 15초 미만일 때만 `GPS_FIX` 플래그가 켜진다.

---

## 6. 개발 환경과 라이브러리

### 6.1 공통

- Arduino IDE 2.x
- Espressif ESP32 Arduino Core
- 시리얼 모니터: `115200 baud`

손목은 Arduino IDE 보드를 `ESP32 Dev Module`로 사용한 업로드가 확인됐다. 벨트는 실제 Heltec
ESP32-S3 LoRa 보드 모델과 일치하는 보드 항목을 선택해야 한다.

### 6.2 손목 라이브러리

| 헤더 | 설치 라이브러리 |
| --- | --- |
| `WiFi.h`, `esp_now.h`, `Wire.h` | ESP32 Arduino Core 내장 |
| `MAX30105.h`, `heartRate.h` | SparkFun MAX3010x Pulse and Proximity Sensor Library |
| `SparkFun_TMP117.h` | SparkFun TMP117 Arduino Library |
| `Adafruit_GFX.h` | Adafruit GFX Library |
| `Adafruit_SSD1306.h` | Adafruit SSD1306 |

### 6.3 벨트 라이브러리

| 헤더 | 설치/출처 |
| --- | --- |
| `WiFi.h`, `esp_now.h`, `esp_wifi.h` | ESP32 Arduino Core 내장 |
| `DHTesp.h` | DHTesp |
| `HT_TinyGPS++.h` | Heltec 패키지에 포함된 TinyGPS++ 계열 헤더 |
| `LoRaWan_APP.h` | 해당 Heltec 보드 패키지/라이브러리 |

`HT_TinyGPS++.h`와 `LoRaWan_APP.h`는 일반 ESP32 보드 패키지에 없을 수 있다. 컴파일 오류가 나면
임의의 다른 LoRa 라이브러리로 바꾸기 전에 실제 Heltec 보드용 Arduino 패키지를 설치한다.

---

## 7. 손목 펌웨어 동작

### 7.1 초기화 순서

1. 시리얼 115200 시작
2. I2C를 SDA GPIO21, SCL GPIO22로 시작
3. ESP-NOW 시작, 수신 콜백 등록, 브로드캐스트 peer 등록
4. OLED 주소 `0x3C` 초기화
5. 진동 모터 GPIO25 출력 설정
6. ADC를 12비트로 설정
7. TMP117 초기화
8. MAX30102 초기화 및 LED/샘플 설정
9. GSR 기준선 측정
10. 시작 진동 120ms

OLED 초기화 실패 시에는 화면만 포기하고 센서·통신을 계속한다. 반면 TMP117 또는 MAX30102 초기화가
실패하면 현재 코드는 `while (1)`로 정지한다.

### 7.2 MAX30102 심박 처리

- IR 원시값이 `50000`을 넘으면 손가락이 있다고 판단한다.
- SparkFun `checkForBeat()`로 박동 시점을 검출한다.
- 박동 간격으로 순간 BPM을 계산한다.
- `45 < BPM < 180`인 값만 유효하게 사용한다.
- 최근 최대 8개의 유효 BPM 평균을 `beatAvg`로 보낸다.
- 손가락이 떨어지면 BPM과 평균 버퍼를 0으로 초기화한다.

이 값은 의료기기 수준의 심박값이 아니며, 센서 접촉압·움직임·주변광의 영향을 받는다.

### 7.3 TMP117 피부온도

TMP117은 1초마다 읽고 `tempC`에 저장한다. 이 값이 벨트 팬 및 현재 단순 상태 FSM의 핵심 입력이다.

### 7.4 GSR

- 시작할 때 50회 기준선 샘플을 모은다.
- 각 샘플은 ADC를 10번 읽어 평균낸 값이다.
- 사용자가 움직이지 않은 상태에서 기준선을 잡아야 한다.
- 이후 200ms마다 필터된 값을 읽는다.
- `gsrDiff = gsrValue - gsrBaseline`로 전송한다.

현재 벨트의 단순 FSM은 GSR을 LoRa로 전달하지만 상태 전이에 사용하지 않는다.

### 7.5 손목의 역할 제한

손목은 상태를 계산하지 않는다. 손목이 수행하는 판단은 센서 전처리와 다음 두 가지 표시 보조뿐이다.

- 벨트 상태 패킷이 3초 이상 오지 않으면 `LINK LOST / CHECK BELT / ESP-NOW WAIT`
- 벨트 상태가 `WARNING` 이상이고 `EMERGENCY` 이하이면 3초 간격으로 짧게 두 번 진동

---

## 8. 손목↔벨트 ESP-NOW 통신

### 8.1 통신 방향

| 방향 | 패킷 | 주기 | 목적 |
| --- | --- | ---: | --- |
| 손목 → 벨트 | `SensorPacket` | 1000ms | BPM, 피부온도, GSR, IR, 손가락 상태 |
| 벨트 → 손목 | `DisplayPacket` | 500ms | 벨트가 계산한 상태, 원인, 팬, 표시값 |

손목은 `FF:FF:FF:FF:FF:FF`로 센서 패킷을 브로드캐스트한다. 벨트는 수신 패킷의 송신 MAC이
코드에 등록된 `34:98:7A:BD:7A:2C`일 때만 받아들인다. 벨트는 같은 MAC으로 표시 패킷을
유니캐스트 회신한다.

### 8.2 손목 MAC 확인과 변경

손목 보드가 바뀌면 벨트의 `gloveMac[]`도 바꿔야 한다. 손목에서 다음 코드로 STA MAC을 확인한다.

```cpp
WiFi.mode(WIFI_STA);
Serial.println(WiFi.macAddress());
```

예를 들어 출력이 `34:98:7A:BD:7A:2C`라면 벨트에 다음과 같이 입력한다.

```cpp
uint8_t gloveMac[] = {0x34, 0x98, 0x7A, 0xBD, 0x7A, 0x2C};
```

### 8.3 `SensorPacket` 현재 레이아웃

현재 구조체에는 `packed`가 없다. ESP32 GCC의 일반 정렬에서는 크기가 28바이트이며 `bool` 뒤에
3바이트 패딩이 들어간다.

| 오프셋 | 크기 | C++ 형식 | 필드 | 의미 |
| ---: | ---: | --- | --- | --- |
| 0 | 4 | `int` | `bpm` | 평균 심박 |
| 4 | 4 | `float` | `temp` | 피부온도 °C |
| 8 | 4 | `int` | `gsr` | GSR ADC 값 |
| 12 | 4 | `int` | `gsrDiff` | 기준선 대비 차이 |
| 16 | 4 | `long` | `ir` | MAX30102 IR 원시값 |
| 20 | 1 | `bool` | `finger` | 손가락 감지 |
| 21 | 3 | 패딩 | — | 구조체 정렬 |
| 24 | 4 | `unsigned long` | `seq` | 송신 순번 |

손목과 벨트의 `SensorPacket` 선언은 필드 순서와 형식이 한 글자도 다르면 안 된다. 한쪽만
`packed`로 바꾸면 크기가 달라져 벨트에서 `SIZE ERROR`가 발생한다. 현재 코드를 유지한다면 양쪽에
다음 검사를 추가하는 것이 안전하다.

```cpp
static_assert(sizeof(SensorPacket) == 28, "SensorPacket ABI changed");
```

장기적으로는 패딩에 의존하지 않도록 고정 폭 형식(`uint8_t`, `int16_t`, `uint32_t`)과 `packed`,
magic, version을 넣은 새 프로토콜로 교체하는 편이 좋다.

### 8.4 `DisplayPacket` 12바이트 레이아웃

`display_protocol.h`와 벨트 코드의 구조체가 반드시 같아야 한다.

| 오프셋 | 크기 | 필드 | 변환/의미 |
| ---: | ---: | --- | --- |
| 0 | 2 | `magic` | `0xD15A`, 전송 바이트는 `5A D1` |
| 2 | 1 | `version` | 현재 `1` |
| 3 | 1 | `state` | `StateCode` |
| 4 | 1 | `cause` | `CauseCode` |
| 5 | 1 | `fanPercent` | 현재 0 또는 100 |
| 6 | 1 | `bpm` | 0~255 |
| 7 | 2 | `skinTemp_x100` | `값 / 100 = °C` |
| 9 | 1 | `flags` | 아래 표 참고 |
| 10 | 2 | `seq` | 표시 패킷 순번 |

`DisplayPacket.flags`는 현재 다음과 같다.

| bit | 의미 |
| ---: | --- |
| 0 | 손가락 감지 |
| 1 | 비상 상태 |
| 2 | 팬 ON |
| 3 | 최근 5초 안에 손목 패킷 수신 |

수신 손목은 길이 12바이트, magic `0xD15A`, version `1`을 모두 통과한 패킷만 사용한다.

### 8.5 ESP-NOW 채널과 보안

양쪽 모두 `channel = 0`, `encrypt = false`다. 현재는 두 장치가 AP에 연결되지 않고 STA 모드만
사용하므로 가까운 거리의 시험에서 동작하지만, 한쪽을 Wi-Fi AP에 연결하면 채널이 바뀌어 통신이
끊길 수 있다. 현장 버전에서는 다음을 권장한다.

- 고정 채널을 명시하고 양쪽을 같은 채널로 설정
- peer 암호화 또는 애플리케이션 인증 추가
- DisplayPacket 수신 시 magic뿐 아니라 송신 MAC도 검증
- 송신 완료 콜백, 손실률, 마지막 정상 sequence를 시리얼에 기록

---

## 9. 벨트 상태 판단과 팬 제어

### 9.1 상태 코드

| 값 | 상태 | 손목 OLED 1줄 |
| ---: | --- | --- |
| 0 | `STATE_BOOT` | `BOOT` |
| 1 | `STATE_BASELINE` | `BASELINE` |
| 2 | `STATE_NORMAL` | `NORMAL` |
| 3 | `STATE_WARNING` | `WARNING` |
| 4 | `STATE_COOLING` | `COOLING` |
| 5 | `STATE_DANGER` | `DANGER` |
| 6 | `STATE_HIGH_RISK` | `HIGH RISK` |
| 7 | `STATE_EMERGENCY` | `EMERGENCY` |
| 8 | `STATE_SENSOR_CHECK` | `SENSOR CHECK` |

현재 코드에는 9개 상태가 모두 정의되어 있지만, 실제 `makeDisplayStatus()`가 생성하는 상태는
`BOOT`, `BASELINE`, `NORMAL`, `WARNING`, `DANGER`, `EMERGENCY`, `SENSOR_CHECK` 7개다.
`COOLING`과 `HIGH_RISK`는 화면 준비는 되어 있으나 현재 조건식에서는 생성되지 않는다.

### 9.2 현재 FSM 판정 우선순위

위에서 먼저 만족한 조건이 최종 상태가 된다.

| 우선 | 조건 | 결과 상태 | 원인 |
| ---: | --- | --- | --- |
| 1 | 비상 버튼 상태 활성 | `EMERGENCY` | `NONE` |
| 2 | 부팅 후 3초 미만 | `BOOT` | `NONE` |
| 3 | 손목 데이터가 없거나 5초 초과, Finger NO, BPM ≤ 0 | `SENSOR_CHECK` | `SENSOR` |
| 4 | 유효 착용이 시작된 후 피부온도 ≥ 30.0°C | `DANGER` | `TEMP_UP` |
| 5 | 피부온도 ≥ 29.0°C | `WARNING` | `TEMP_UP` |
| 6 | 유효 착용 후 기준선 10초 미만 | `BASELINE` | `NONE` |
| 7 | 나머지 | `NORMAL` | `NONE` |

주의할 점은 온도 조건이 기준선 완료 여부보다 먼저 검사된다는 것이다. 기준선 측정 중이라도 피부온도가
29°C 이상이면 즉시 `WARNING` 또는 `DANGER`가 된다.

현재 FSM은 GitHub `algorithm/`의 전체 RiskIndex v0.2 알고리즘을 벨트에 포팅한 것이 아니다.
현재 실물 벨트 판정은 피부온도, 손가락/BPM 유효성, 비상 버튼을 이용한 단순 MVP 로직이다. BPM,
GSR, 환경온도는 LoRa 텔레메트리에 포함되지만 `makeDisplayStatus()`의 상태 계산에는 아직 사용되지
않는다.

### 9.3 팬 제어

| 조건 | 팬 1 | 팬 2 |
| --- | --- | --- |
| 비상 활성 | ON | ON |
| 손목 데이터가 없거나 5초 초과 | OFF | OFF |
| 유효 손목 피부온도 ≥ 30.0°C | ON | ON |
| 그 외 | OFF | OFF |

현재 제어는 디지털 ON/OFF이며 실제 PWM 50% 단계는 없다. 따라서 현재 `fanPercent`는 0 또는 100만
전달된다. `STATE_COOLING`의 `FAN 50%` 문구를 실제로 사용하려면 PWM 채널과 듀티 제어를 추가해야 한다.

### 9.4 비상 버튼의 정확한 동작

버튼을 누르면 즉시 `emergencyActive = true`가 되고 팬이 켜진다. 버튼이 눌린 동안
`lastButtonPressTime`이 계속 갱신되며, 버튼에서 손을 뗀 뒤 5초가 지나면 자동으로 비상 상태가
해제된다.

즉, 현재 코드는 “5초 길게 눌러 해제”가 아니라 **“마지막으로 눌린 시점부터 5초 동안 비상 유지”**다.
GitHub 서버 문서의 “현장 물리 확인 전까지 EMERGENCY 래치 유지” 정책과 정확히 맞추려면 향후
별도의 해제 동작을 구현해야 한다.

---

## 10. 손목 OLED 표시

OLED는 `SSD1306 128x64`, I2C 주소 `0x3C`를 사용한다. 벨트에서 받은 상태가 3초 안에 갱신됐을
때만 정상 화면을 표시한다.

| 벨트 상태 | 1줄 | 2줄 |
| --- | --- | --- |
| `BOOT` | `BOOT` | `STARTING` |
| `BASELINE` | `BASELINE` | `STAY STILL` |
| `NORMAL` | `NORMAL` | `HR <bpm> T <temp>C` |
| `WARNING` | `WARNING` | 원인 문자열 |
| `COOLING` | `COOLING` | `FAN <percent>% <cause>` |
| `DANGER` | `DANGER` | `FAN 100% <cause>` |
| `HIGH_RISK` | `HIGH RISK` | `FAN 100%` |
| `EMERGENCY` | `EMERGENCY` | `SOS FAN 100%` |
| `SENSOR_CHECK` | `SENSOR CHECK` | `WEAR GLOVE` |
| 패킷 3초 초과 | `LINK LOST` | `CHECK BELT`, `ESP-NOW WAIT` |

원인 코드는 다음과 같이 표시된다.

| 원인 코드 | OLED 문구 |
| --- | --- |
| `CAUSE_HR_HIGH` | `HR HIGH` |
| `CAUSE_HR_CHANGE` | `HR CHANGE` |
| `CAUSE_TEMP_UP` | `TEMP UP` |
| `CAUSE_GSR_UP` | `GSR UP` |
| `CAUSE_HOT_ENV` | `HOT ENV` |
| `CAUSE_ACTIVE` | `ACTIVE` |
| `CAUSE_SENSOR` | `CHECK BODY` |

---

## 11. 벨트→베이스 LoRa 통신

### 11.1 무선 설정

송신기와 수신기는 다음 값이 모두 같아야 한다.

| 항목 | 값 |
| --- | ---: |
| 주파수 | `922300000 Hz` |
| 출력 | `10 dBm` |
| 대역폭 | `0` — Heltec API의 125kHz 설정 |
| Spreading Factor | `7` |
| Coding Rate | `1` — 4/5 |
| Preamble | `8` symbols |
| 고정 길이 payload | `false` |
| IQ inversion | `false` |
| Radio CRC | `true` |
| 송신 주기 | 2000ms |

주파수·출력·안테나는 실제 사용 국가의 최신 전파 규정과 해당 보드 인증 범위를 별도로 확인해야 한다.

### 11.2 `TelemetryPacket` 35바이트

구조체는 `packed`이며 ESP32 little-endian 순서로 그대로 전송된다. Python 디코더 형식은
`<HBBHBhHhIhHiiBhHB`다.

| 오프셋 | 크기 | 필드 | 단위/변환 |
| ---: | ---: | --- | --- |
| 0 | 2 | `magic` | `0xA55A`, 전송 바이트 `5A A5` |
| 2 | 1 | `version` | `1` |
| 3 | 1 | `nodeId` | 현재 `1` |
| 4 | 2 | `seq` | 0~65535 순환 |
| 6 | 1 | `bpm` | bpm |
| 7 | 2 | `skinTemp_x100` | `/100 = °C` |
| 9 | 2 | `gsr` | 0~65535 |
| 11 | 2 | `gsrDiff` | signed |
| 13 | 4 | `ir` | MAX30102 IR |
| 17 | 2 | `airTemp_x10` | `/10 = °C` |
| 19 | 2 | `humidity_x10` | `/10 = %` |
| 21 | 4 | `latitude_e7` | `/10,000,000 = °` |
| 25 | 4 | `longitude_e7` | `/10,000,000 = °` |
| 29 | 1 | `satellites` | 위성 수 |
| 30 | 2 | `altitude_dm` | `/10 = m` |
| 32 | 2 | `speed_x10` | `/10 = km/h` |
| 34 | 1 | `flags` | 유효성·상태 비트 |

### 11.3 LoRa flags

| bit | 마스크 | 의미 |
| ---: | ---: | --- |
| 0 | `0x01` | 최근 5초 안에 손목 데이터 수신 |
| 1 | `0x02` | 현재 DHT11 읽기 유효 |
| 2 | `0x04` | GPS 위치 유효, age < 15초 |
| 3 | `0x08` | 손가락 감지 |
| 4 | `0x10` | 비상 활성 |
| 5 | `0x20` | 팬 ON |
| 6~7 | — | 예약 |

저장소의 `common/glove_packets.py` 디코더는 35바이트 구조를 정확히 풀지만 현재
`TelemetryFlags` 열거형에는 bit 0~3만 이름이 정의돼 있다. 비상·팬을 사용하려면 다음 두 값을
추가하거나 정수 마스크로 검사해야 한다.

```python
EMERGENCY = 1 << 4
FAN_ON = 1 << 5
```

### 11.4 값이 0일 때의 해석

0 자체만 보고 센서값이 유효하다고 판단하면 안 된다. 반드시 flags를 함께 본다.

- bit 0이 0이면 BPM, 피부온도, GSR, IR은 사용할 수 없는 값이다.
- bit 1이 0이면 환경온도와 습도는 사용할 수 없는 값이다.
- bit 2가 0이면 위도·경도 0은 실제 좌표가 아니라 “Fix 없음”이다.
- Finger NO 또는 BPM 0은 위험도 0이 아니라 `SENSOR CHECK` 계열로 처리해야 한다.

### 11.5 sequence 순환

LoRa `seq`는 `uint16_t`이므로 2초 주기에서 약 36.4시간 후 65535에서 0으로 돌아간다. FastAPI
게이트웨이는 기존 sequence보다 작거나 같은 요청을 중복으로 거부하므로, 브리지에서 다음과 같이
32비트 이상 확장 sequence를 만드는 것이 필요하다.

```text
last_raw가 65000 근처이고 new_raw가 0 근처이면 wrap_count += 1
extended_sequence = wrap_count * 65536 + new_raw
```

벨트가 재부팅되어 sequence가 0이 되는 경우도 있으므로 nodeId별 부팅 세션 또는 브리지의 재시작
정책을 정해야 한다.

---

## 12. LoRa 데이터를 대시보드에 연결하기

### 12.1 실제 데이터 경로

```text
벨트 Radio.Send(35B)
  → 베이스 LoRa 수신기 OnRxDone(payload, size, rssi, snr)
  → USB Serial 또는 로컬 프로세스로 35B 전달
  → common.glove_packets.decode_glove_telemetry(payload)
  → TelemetryV2 JSON 생성
  → POST http://127.0.0.1:8000/ingest/telemetry
  → FastAPI 검증·SQLite 저장·WebSocket broadcast
  → React 대시보드 즉시 갱신
```

`common/glove_packets.py`는 디코더일 뿐 LoRa 라디오를 직접 읽지 않는다. 수신 보드의
`OnRxDone()`은 다음 요구조건을 만족해야 한다.

1. 벨트와 LoRa 설정이 완전히 같아야 한다.
2. 수신 길이가 정확히 35인지 확인한다.
3. 첫 두 바이트가 `5A A5`인지 확인한다.
4. payload 전체, RSSI, SNR을 게이트웨이 PC에 전달한다.
5. 다음 패킷을 받도록 다시 RX 연속 모드에 들어간다.

권장 시리얼 한 줄 형식은 다음과 같다.

```json
{"payload_hex":"5aa501010100...총35바이트...","rssi_dbm":-71,"snr_db":8}
```

### 12.2 현재 35바이트를 그대로 쓰는 최소 브리지

다음은 수신기에서 `payload: bytes`, `rssi: int`, `snr: int`를 얻은 뒤 사용할 변환의 기준이다.
현재 패킷에는 벨트의 state와 RiskIndex가 없으므로 `risk_index=255`로 두고 제한된 상태만 추정한다.

```python
from datetime import datetime, timezone
import time
import requests

from common.glove_packets import decode_glove_telemetry

GATEWAY_URL = "http://127.0.0.1:8000/ingest/telemetry"
DEVICE_KEY = ""  # 서버에서 키를 설정했을 때만 입력

def utc_now() -> str:
    return (
        datetime.now(timezone.utc)
        .isoformat(timespec="milliseconds")
        .replace("+00:00", "Z")
    )

def convert_packet(payload: bytes, rssi: int, snr: int, extended_seq: int) -> dict:
    p = decode_glove_telemetry(payload)
    flags = int(p.flags)

    glove_ok = bool(flags & (1 << 0))
    dht_ok = bool(flags & (1 << 1))
    gps_ok = bool(flags & (1 << 2))
    finger_ok = bool(flags & (1 << 3))
    emergency = bool(flags & (1 << 4))
    fan_on = bool(flags & (1 << 5))

    active_errors = []
    if not glove_ok or not finger_ok or p.bpm <= 0:
        active_errors.append("SENSOR_CHECK")
    if not dht_ok:
        active_errors.append("DHT_INVALID")
    if not gps_ok:
        active_errors.append("GPS_NO_FIX")

    # 35B v1에는 정확한 벨트 state가 없으므로 가능한 범위만 표현한다.
    if emergency:
        state = "EMERGENCY"
    elif not glove_ok or not finger_ok or p.bpm <= 0:
        state = "FAULT"
    elif fan_on:
        state = "COOLING"
    else:
        state = "NORMAL"

    return {
        "schema_version": "2.0",
        "gateway_utc": utc_now(),
        "device_id": f"HS-W-{p.node_id:03d}",
        "monotonic_ms": int(time.monotonic() * 1000),
        "state": state,
        "risk_index": 255,
        "valid_weight": 1.0 if glove_ok and finger_ok else 0.0,
        "quality": {
            "ppg": 100 if glove_ok and finger_ok and p.bpm > 0 else 0,
            "skin": 100 if glove_ok else 0,
            "eda": 100 if glove_ok else 0,
            "imu": 0,
        },
        "signals": {
            "hr_bpm": p.bpm if glove_ok else 0,
            "skin_c": p.skin_temp_c if glove_ok else 0.0,
            "activity": "UNKNOWN",
        },
        "cooling": {
            "requested": 4 if emergency else (2 if fan_on else 0),
            "actual_pwm": 100 if fan_on else 0,
            "current_ma": 0,
        },
        "contributions": {},
        "active_errors": active_errors,
        "raw": {
            "gsr": p.gsr if glove_ok else None,
            "gsr_diff": p.gsr_diff if glove_ok else None,
            "ir": p.ir if glove_ok else None,
            "air_temp_c": p.air_temp_c if dht_ok else None,
            "humidity_percent": p.humidity_percent if dht_ok else None,
            "finger_detected": finger_ok,
            "glove_data": glove_ok,
            "dht_data": dht_ok,
            "gps_fix": gps_ok,
            "latitude": p.latitude if gps_ok else None,
            "longitude": p.longitude if gps_ok else None,
        },
        "radio": {"rssi_dbm": rssi, "snr_db": snr},
        "config_version": "hardware-mvp-1",
        "sequence": extended_seq,
    }

def post_telemetry(data: dict) -> None:
    headers = {"X-HS-Device-Key": DEVICE_KEY} if DEVICE_KEY else {}
    response = requests.post(GATEWAY_URL, json=data, headers=headers, timeout=3)
    response.raise_for_status()
```

이 방식으로 장치 카드의 BPM, 피부온도, GSR, 환경온도·습도, Finger, RSSI, GPS와 지도는 표시할
수 있다. 그러나 `WARNING`과 `DANGER`, 정확한 RiskIndex는 패킷에 없으므로 복원할 수 없다.

### 12.3 벨트 판정을 그대로 대시보드에 띄우는 권장 확장

“상태는 벨트에서만 계산한다”는 설계를 유지하려면 LoRa 패킷에 최소 다음 4바이트를 추가한다.

```cpp
uint8_t state;       // StateCode
uint8_t cause;       // CauseCode
uint8_t fanPercent;  // 0~100
uint8_t riskIndex;   // 0~100, 계산 전/불가 255
```

현재 35바이트 뒤에 붙이면 version 2의 총 길이는 39바이트가 된다. 이때 반드시 다음을 함께 변경한다.

1. 벨트 `TelemetryPacket`에 네 필드를 추가하고 `version = 2`로 올린다.
2. `static_assert(sizeof(TelemetryPacket) == 39)`로 확인한다.
3. `common/glove_packets.py`가 version/길이에 따라 v1 35B와 v2 39B를 각각 해석하게 한다.
4. 브리지는 패킷의 state/cause/fan/risk를 `TelemetryV2`로 그대로 변환한다.
5. GitHub `common/schema.py`와 `dashboard/src/types/device.ts`에 필요한 상태를 추가한다.

현재 서버/대시보드의 상태 이름은 다음 7개만 허용한다.

```text
BOOT, BASELINE, NORMAL, WARNING, COOLING, EMERGENCY, FAULT
```

실물 벨트의 상태를 손실 없이 표시하려면 다음 3개도 허용하고 UI 라벨/색상을 정의한다.

```text
DANGER, HIGH_RISK, SENSOR_CHECK
```

수정 대상은 다음과 같다.

| 파일 | 필요한 변경 |
| --- | --- |
| `common/schema.py` | `DeviceStateName` Literal 확장 |
| `dashboard/src/types/device.ts` | `DeviceState`, 순서, 한국어 라벨 확장 |
| `dashboard/src/components/DeviceCard.tsx` | 상태별 카드 CSS 분류 확장 |
| `server/app/state.py` | 어떤 상태에서 alert/emergency를 열지 정책 확정 |
| 테스트 | 새 상태 JSON 수용과 WebSocket 표시 검증 |

반대로 저장소의 7상태 체계를 유지하려면 `DANGER/HIGH_RISK`를 `COOLING`으로, `SENSOR_CHECK`를
`FAULT + active_errors=["SENSOR_CHECK"]`로 매핑할 수 있다. 이 방식은 구현은 간단하지만 벨트 상태의
세부 정보가 사라진다.

---

## 13. FastAPI 게이트웨이 동작

### 13.1 입력

브리지는 다음 주소로 `TelemetryV2` JSON을 보낸다.

```http
POST /ingest/telemetry
Content-Type: application/json
X-HS-Device-Key: <장치 키를 설정한 경우>
```

`server/app/routes_ingest.py`가 Pydantic `TelemetryV2`로 자료형과 범위를 검증한다. 장치 키 설정이
비어 있으면 개발 모드로 인증 없이 받으며, 실제 운용에서는 `HEATSENTRY_DEVICE_KEYS`를 설정한다.

### 13.2 저장과 중복 제거

`server/app/state.py`의 `GatewayStore.ingest_telemetry()`가 다음을 수행한다.

1. 같은 device_id의 마지막 sequence와 비교
2. 새 sequence가 더 크지 않으면 `duplicate_ignored`
3. 최신 장치 상태를 메모리에 갱신
4. SQLite에 텔레메트리와 마지막 장치 상태 저장
5. WebSocket으로 `{"type":"telemetry","data":...}` 전송
6. 이전 state와 다르면 `STATE_CHANGE` 이벤트 생성
7. 이벤트에 이전 해시를 연결하여 해시체인 저장
8. WARNING/COOLING이면 경보, EMERGENCY이면 응급 레코드 생성

기본 SQLite 파일은 `server/heatsentry_gateway.db`이며 `HEATSENTRY_DB_PATH`로 변경할 수 있다.

### 13.3 대시보드 출력

대시보드는 시작할 때 `ws://127.0.0.1:8000/ws/live`에 연결한다.

- 연결 직후 서버는 최신 장치와 최근 이벤트 50개의 `snapshot`을 보낸다.
- 이후 새 텔레메트리는 `telemetry`, 이벤트는 `event` 메시지로 즉시 전달된다.
- WebSocket이 끊기면 `/api/v2/devices`와 `/api/v2/events`를 1.5초마다 REST 폴링한다.
- 장치별 최근 유효 RiskIndex 최대 60개를 위험도 추이에 사용한다.

`DeviceCard.tsx`는 다음을 표시한다.

- 장치 ID와 상태
- RiskIndex
- 심박과 피부온도
- 팬 출력과 냉각 단계
- 가장 큰 위험 기여 원인
- 센서 오류
- GSR, 환경온도·습도, Finger, LoRa RSSI, GPS 위치

`TacticalMap.tsx`는 `raw.gps_fix == true`이고 위도·경도가 유한한 장치만 지도에 표시한다.

---

## 14. 서버와 대시보드 실행

다음 명령은 Windows PowerShell 기준이다.

### 14.1 저장소 준비

```powershell
git clone https://github.com/yeoniix/heatsentry-tac.git
Set-Location heatsentry-tac
py -m venv .venv
.\.venv\Scripts\Activate.ps1
pip install -r server\requirements.txt
```

### 14.2 개발 모드 서버

```powershell
uvicorn server.app.main:app --reload --port 8000
```

브라우저에서 `http://127.0.0.1:8000/`을 열어 다음과 비슷한 응답을 확인한다.

```json
{"message":"HeatSentry gateway (schema_version 2.0) is running","time":"..."}
```

### 14.3 장치 키를 사용하는 서버

```powershell
$env:HEATSENTRY_DEVICE_KEYS='{"HS-W-001":"충분히-긴-임의-비밀키"}'
$env:HEATSENTRY_CORS_ORIGINS='http://127.0.0.1:5173,http://localhost:5173'
uvicorn server.app.main:app --host 0.0.0.0 --port 8000
```

브리지의 `X-HS-Device-Key`도 같은 키여야 한다. 키와 지도 API 키는 Git에 커밋하지 않는다.

### 14.4 대시보드

```powershell
Set-Location dashboard
npm install
Copy-Item .env.example .env.local
npm run dev
```

기본 주소는 `http://localhost:5173`이다. 게이트웨이가 다른 PC에 있으면 `.env.local`에 다음을
추가한다.

```dotenv
VITE_GATEWAY_URL=http://게이트웨이_IP:8000
VITE_KAKAO_MAP_APP_KEY=카카오_JavaScript_키
```

카카오 Developers의 Web 플랫폼에도 `http://localhost:5173`과 실제 운영 도메인을 등록해야 한다.
지도 키가 없어도 장치 카드와 나머지 대시보드는 작동하고, 지도 영역에는 설정 안내가 나온다.

### 14.5 실행 순서

1. FastAPI 게이트웨이 실행
2. LoRa 베이스 수신기 연결
3. LoRa→HTTP 브리지 실행
4. React 대시보드 실행
5. 벨트 전원 ON
6. 손목 전원 ON 및 착용
7. 시리얼과 대시보드에서 sequence가 증가하는지 확인

---

## 15. 펌웨어 업로드와 확인 절차

### 15.1 손목

1. `display_protocol.h`를 `.ino`와 같은 Arduino 스케치 폴더에 둔다.
2. 보드 `ESP32 Dev Module`, 올바른 COM 포트를 선택한다.
3. 업로드 속도가 921600에서 불안정하면 460800 또는 115200으로 낮춘다.
4. 업로드 후 시리얼 모니터를 115200으로 연다.
5. 다음 로그를 확인한다.

```text
Calibrating GSR... keep still.
System ready
GSR baseline = ...
Finger=..., IR=..., BPM=..., Avg BPM=..., Temp=..., GSR=..., GSRdiff=..., Alert=...
```

`Hash of data verified`와 `Hard resetting via RTS pin`은 업로드 성공이다.

### 15.2 벨트

1. 실제 Heltec 보드 모델을 선택한다.
2. DHT11 DATA가 GPIO33인지 다시 확인한다.
3. 손목 MAC이 `gloveMac[]`와 같은지 확인한다.
4. 시리얼 모니터 115200에서 다음 초기화 로그를 확인한다.

```text
[OK] MCU
[OK] BUTTON GPIO7
[OK] FAN1 GPIO6
[OK] FAN2 GPIO47
[OK] DHT11 GPIO33
[OK] GPS UART
[OK] GLOVE PEER
[OK] ESP-NOW
[OK] LoRa TX
Telemetry Size : 35 bytes
Display Size   : 12 bytes
SYSTEM READY
```

### 15.3 정상 데이터 흐름

벨트 시리얼에서 다음을 순서대로 확인한다.

```text
[ GLOVE / ESP32U ]
BPM          : ...
Skin Temp    : ...
Finger       : YES
ESP-NOW age  : 0~수천 ms

[ DHT11 ]
Air Temp     : ...
Humidity     : ...

[ GPS ]
GPS chars    : 계속 증가
Fix          : YES

LoRa bytes   : 35
>>> LoRa TX DONE <<<
```

---

## 16. 단계별 통합 시험

한 번에 전체를 켜기보다 아래 순서로 시험하면 고장 위치를 빠르게 찾을 수 있다.

### 시험 A — 손목 센서 단독

- 손가락을 올리면 `Finger=YES`, IR > 50000
- 몇 초 후 `Avg BPM`이 45~180 범위
- TMP117 온도가 출력
- GSR과 GSRdiff가 출력

### 시험 B — 손목 OLED 단독

- I2C 스캐너에서 `0x3C`, `0x48`, `0x57` 확인
- 부팅 시 `HEATSENTRY / STARTING`
- 벨트가 없으면 3초 이후 `LINK LOST`

### 시험 C — ESP-NOW 왕복

- 벨트에서 `NO DATA`가 아닌 손목 센서값 출력
- 손목 OLED에서 `SENSOR CHECK`, `BASELINE`, `NORMAL` 순서 확인
- 벨트 전원을 끄면 3초 이내 손목에 `LINK LOST`

### 시험 D — 팬

- 시험용으로 피부온도 임계값을 안전하게 시뮬레이션하거나 코드의 테스트 상수를 임시 사용
- 29°C 이상 30°C 미만에서 `WARNING`, 팬 OFF
- 30°C 이상에서 `DANGER`, 팬 두 개 ON
- 테스트 후 임계값을 원래 값으로 복구

### 시험 E — DHT11 노이즈

- 팬 OFF에서 연속 DHT 성공
- 팬 ON에서도 캐패시터 적용 후 대부분 성공
- 실패 시 `[DHT11] retry` 후 회복하는지 확인
- 팬 ON 때만 계속 실패하면 전원·배선 분리와 드라이버 억제를 보강

### 시험 F — GPS

- `GPS chars`가 증가하면 UART 배선 정상
- 야외에서 위성 수와 위치 Fix 확인
- Fix 후 flags bit2, 즉 `0x04`가 포함되는지 확인

### 시험 G — LoRa

- 벨트 `LoRa bytes : 35`
- 벨트 `LoRa TX DONE`
- 베이스 수신 길이 35
- payload 시작 `5A A5 01 01`
- RSSI/SNR 기록

### 시험 H — 서버·대시보드

- 브리지 POST 응답 `status: ok`
- `/api/v2/devices`에 `HS-W-001` 생성
- 대시보드 카드의 seq가 증가
- GPS Fix 후 지도 마커 표시
- WebSocket을 끊어도 1.5초 REST 폴링으로 갱신

---

## 17. 문제 해결표

| 증상 | 가능한 원인 | 확인/해결 |
| --- | --- | --- |
| 손목 시리얼이 완전히 비어 있음 | 잘못된 COM 포트, baud, 업로드 실패, 전원 문제 | COM 확인, 115200, 리셋 버튼, USB 데이터 케이블 확인 |
| 업로드 중 `Unable to verify flash chip connection` | 921600 업로드 불안정, USB 케이블/허브, 전원 노이즈 | 업로드 속도 낮춤, 허브 제거, 센서/모터 전원 분리 후 업로드 |
| 벨트 `NO DATA` | 손목 MAC 불일치, ESP-NOW 채널, 손목 미부팅 | STA MAC 재확인, 양쪽 채널 통일, 손목 로그 확인 |
| 벨트 `SIZE ERROR` | SensorPacket 선언/정렬 불일치 | 양쪽 선언 비교, `sizeof` 28 확인 |
| 손목 OLED `LINK LOST` | 벨트 송신 실패, peer MAC 불일치, 3초 timeout | 벨트 `[DISPLAY] SEND ERROR`, MAC, 전원 확인 |
| OLED가 검은 화면 | 주소가 0x3C 아님, SDA/SCL 반대, 전원 문제 | I2C 스캐너, 주소 변경, GPIO21/22 확인 |
| MAX30102/TMP117 init failed | I2C 배선/전원/주소 문제 | 센서 하나씩 연결, I2C 스캔, 풀업 확인 |
| 심박 0 | 손가락 없음, IR < 50000, 움직임, 광학 접촉 불량 | IR 로그 확인, 밀착, LED 세기/임계값 조정 |
| DHT11 READ FAILED | 모터 노이즈, 전원 강하, 배선, 손상 | GPIO33, 100uF+0.1uF, 전원 분리, 센서 교체 |
| GPS chars 0 | GPS TX와 GPIO38 미연결, baud/전원 문제 | TX→RX 교차 배선, 9600bps 확인 |
| GPS chars 증가하지만 NO FIX | 실내, 안테나 간섭, 콜드 스타트 | 야외 이동, 안테나 이격, 충분히 대기 |
| `LoRa TX DONE`인데 베이스 무수신 | 주파수/SF/BW/CR/IQ 불일치, 안테나 | 표 11.1 전체 대조, 안테나 연결 |
| 서버 POST 422 | TelemetryV2 필드/범위/상태 불일치 | 응답 body의 validation error 확인 |
| 서버 `duplicate_ignored` | sequence 중복/감소/16비트 wrap | 확장 sequence 구현 |
| 카드에는 뜨지만 지도 없음 | `gps_fix=false`, 좌표 null, Kakao 키/도메인 | JSON raw, `.env.local`, Kakao 플랫폼 확인 |
| DANGER를 POST하면 422 | 현재 서버 상태 enum에 DANGER 없음 | 스키마 확장 또는 COOLING으로 명시적 매핑 |
| RiskIndex가 `—` | 35B 패킷에 RiskIndex 없음, 값 255 | 전체 알고리즘 포팅 또는 v2 패킷 확장 |

---

## 18. 현재 구현의 제한과 다음 개선 순서

### 필수 통합 작업

1. 베이스 LoRa 수신기와 시리얼 출력 구현
2. 시리얼→35B 디코더→`POST /ingest/telemetry` 브리지 구현
3. 16비트 LoRa sequence wrap 처리
4. bit4 Emergency와 bit5 Fan을 Python enum에 추가
5. 실제 벨트 상태를 보낼지, 대시보드에서 축약 매핑할지 결정

### 정확도·기능 개선

1. GitHub의 전체 RiskIndex/FSM을 벨트에 포팅하거나 벨트용 경량판으로 명세
2. BPM·GSR·환경온도를 벨트 상태 계산에 반영
3. `COOLING`, `HIGH_RISK` 전이 조건 구현
4. 팬 PWM 50/100% 단계 구현
5. 팬 전류·회전 검출을 추가해 “명령”과 “실제 동작”을 구분
6. 배터리 전압/잔량 측정 추가

### 통신 신뢰성 개선

1. SensorPacket을 고정 폭 packed/versioned 형식으로 교체
2. ESP-NOW 채널 고정과 암호화
3. DisplayPacket 송신자 MAC 검증
4. LoRa 애플리케이션 수준 CRC 또는 메시지 인증 추가
5. 패킷 손실률, RSSI/SNR, 마지막 수신 age 관제 표시

### 안전 정책 정합성 개선

1. 현재 5초 자동 해제 비상 동작과 “현장 확인 전까지 래치” 정책 중 하나를 공식 결정
2. 팬 드라이버 고장·과전류·저전압 시 안전 상태 정의
3. 센서 데이터가 오래됐을 때 팬을 끄는 현재 정책이 요구사항에 맞는지 위험 분석
4. 대시보드 확인과 실제 장치 비상 해제를 계속 분리

---

## 19. 재현 완료 체크리스트

### 손목

- [ ] ESP32 Dev Module에 손목 코드 업로드
- [ ] I2C GPIO21/22 확인
- [ ] OLED `0x3C`, TMP117 `0x48`, MAX30102 `0x57` 확인
- [ ] GSR AO GPIO34 확인
- [ ] 진동 모터 구동회로 GPIO25 확인
- [ ] 손목 STA MAC 기록
- [ ] Finger, BPM, TMP117, GSR 시리얼 확인

### 벨트

- [ ] Heltec 보드 모델과 Arduino 보드 설정 일치
- [ ] `gloveMac[]`를 실제 손목 MAC으로 설정
- [ ] DHT11 DATA GPIO33
- [ ] DHT11 VCC-GND 100uF, 필요 시 0.1uF 병렬
- [ ] GPS TX→GPIO38, GPS RX←GPIO39, 9600bps
- [ ] 비상 버튼 GPIO7-GND
- [ ] 팬 드라이버 GPIO6/GPIO47, 공통 GND
- [ ] TelemetryPacket 35B, DisplayPacket 12B 확인

### 로컬 폐루프

- [ ] 손목→벨트 센서 1초 전송
- [ ] 벨트→손목 상태 0.5초 전송
- [ ] 3초 통신 손실 화면 확인
- [ ] 기준선 10초 후 NORMAL 확인
- [ ] WARNING/DANGER/EMERGENCY와 팬 확인
- [ ] 경고 진동 확인

### LoRa·관제

- [ ] 양쪽 LoRa 설정 일치
- [ ] 베이스에서 35B와 magic 수신
- [ ] RSSI/SNR 확보
- [ ] 브리지에서 flags 기반 null/유효값 처리
- [ ] sequence wrap 처리
- [ ] FastAPI `/ingest/telemetry` 응답 ok
- [ ] 장치 카드 실시간 갱신
- [ ] GPS Fix 후 지도 표시
- [ ] 실제 벨트 state 전달 방식 결정 및 문서/코드 동기화

---

## 20. 한 문장 요약

현재 HeatSentry 실물 시스템은 **손목이 생체센서를 측정해 ESP-NOW로 벨트에 보내고, 벨트가 상태와
팬을 결정해 손목 OLED로 되돌려 주며, 전체 원시 데이터를 35바이트 LoRa로 송신하는 로컬 폐루프**다.
대시보드까지 완전하게 연결하려면 **베이스 LoRa 수신·HTTP 브리지와 벨트 state/RiskIndex 전달
계약**을 마지막으로 확정해야 한다.

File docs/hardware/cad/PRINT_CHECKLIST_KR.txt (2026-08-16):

HeatSentry V7 TRUE FINAL - 출력 전 마지막 체크

1. 실제 fan 외형이 40 x 40 x 약 10.3 mm인지 확인
2. fan screw pitch가 32 x 32 mm인지 확인
3. power bank가 140 x 70 x 15 mm envelope 이하인지 확인
4. ESP mounted depth가 25 mm 이하인지 확인
5. 사용할 hose의 실제 OD가 32 mm 또는 25 mm 중 무엇인지 확인
6. M3 heat-set insert 실제 OD에 4.2 mm pilot가 맞는지 작은 테스트 보스로 먼저 확인
7. service cover는 220 x 220 bed에서 약 45도 회전 배치
8. fan grille 1개를 먼저 출력해 fan hole pitch/필터 두께만 실물 확인
9. 이상 없으면 shell -> cover -> mounts 순으로 본 출력

이 체크는 재설계를 위한 단계가 아니라 실제 부품 제조공차/프린터 수축을 잡기 위한 one-time fit check입니다.

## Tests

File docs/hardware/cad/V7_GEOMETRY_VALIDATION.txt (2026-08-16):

HeatSentry V7 TRUE FINAL — CAD geometry validation

STL topology: PASS
- 01_LEFT_SHELL_V7.stl: components=1, watertight=True, bbox=124.2 x 72.1 x 108.0 mm
- 02_RIGHT_SHELL_V7.stl: components=1, watertight=True, bbox=120.2 x 72.1 x 113.5 mm
- 03B_SERVICE_COVER_FLAT_NO_PCM_V7.stl: components=1, watertight=True, bbox=216.0 x 2.8 x 82.0 mm
- 03_SERVICE_COVER_PCM_READY_V7.stl: components=1, watertight=True, bbox=216.0 x 8.8 x 82.0 mm
- 04_BATTERY_CRADLE_140x70_V7.stl: components=1, watertight=True, bbox=146.0 x 8.4 x 73.5 mm
- 05_ESP_UNIVERSAL_SLED_V7.stl: components=1, watertight=True, bbox=36.0 x 1.6 x 62.0 mm
- 06_CENTER_BRIDGE_PLATE_PRINT_2X_V7.stl: components=1, watertight=True, bbox=40.0 x 3.0 x 10.0 mm
- 07_BELT_LOOP_LEFT_50mm_V7.stl: components=1, watertight=True, bbox=11.8 x 22.0 x 70.0 mm
- 08_BELT_LOOP_RIGHT_50mm_V7.stl: components=1, watertight=True, bbox=11.8 x 22.0 x 70.0 mm
- 09_FAN_FILTER_GRILLE_40mm_PRINT_2X_V7.stl: components=1, watertight=True, bbox=48.0 x 3.0 x 48.0 mm
- 10_PCM_CARRIER_UNIVERSAL_V7.stl: components=1, watertight=True, bbox=172.0 x 10.4 x 76.0 mm
- 11_DUCT_ADAPTER_TO_32mm_OD_HOSE_V7.stl: components=1, watertight=True, bbox=50.0 x 38.0 x 20.0 mm
- 12_DUCT_ADAPTER_TO_25mm_OD_HOSE_COMPAT_V7.stl: components=1, watertight=True, bbox=50.0 x 38.0 x 20.0 mm

Assembly interference checks: PASS
- left_vs_right: 0.000000 mm^3
- shell_vs_pcm_cover: 0.000000 mm^3
- shell_vs_flat_cover: 0.000000 mm^3
- shell_vs_fan_left_ref: 0.000000 mm^3
- shell_vs_fan_right_ref: 0.000000 mm^3
- shell_vs_powerbank_ref: 0.000000 mm^3
- shell_vs_esp_ref: 0.000000 mm^3
- battery_cradle_vs_powerbank_ref: 0.000000 mm^3
- esp_sled_vs_esp_ref: 0.000000 mm^3
- left_belt_loop_vs_left_shell: 0.000000 mm^3
- right_belt_loop_vs_right_shell: 0.000000 mm^3
- pcm_carrier_vs_pcm_cover: 0.000000 mm^3
- pcm_carrier_vs_pcm_ref: 0.000000 mm^3

Key geometry
- left_shell_solids: 1
- right_shell_solids: 1
- air_chamber_depth_mm: 30.900
- electronics_depth_mm: 33.900
- fan_back_plenum_depth_mm: 20.550
- fan_backer_open_area_mm2: 1075.210
- top_port_open_area_mm2: 894.929
- top_port_to_fan_backer_area_ratio: 0.832
- esp_rear_clearance_mm: 5.400
- powerbank_rear_clearance_mm: 10.200
- cover_45deg_square_footprint_mm: 210.718
- rear_service_opening_mm: [204.0, 74.0]
- wall_mm: 2.400
- top_riser_height_mm: 18.000

Notes
- PASS means CAD-level topology/interference checks passed. It is not a physical IP rating or a substitute for a real fit/leak test with the purchased hardware.
- The entire wearable cannot be IP67 while its cooling airflow path is intentionally open. The electronics bay is isolated by an integral separator and gasketed service cover; actual ingress protection requires physical testing.

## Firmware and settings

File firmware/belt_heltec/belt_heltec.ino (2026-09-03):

#include "display_protocol.h"
#include <Wire.h>
#include <WiFi.h>
#include <esp_now.h>
#include "MAX30105.h"
#include "heartRate.h"
#include "SparkFun_TMP117.h"
#include <Adafruit_GFX.h>
#include <Adafruit_SSD1306.h>

// ===================== 핀 설정 =====================
#define I2C_SDA_PIN 21
#define I2C_SCL_PIN 22
#define GSR_PIN     34
#define MOTOR_PIN   25

// ===================== OLED 128x64 I2C =====================
#define SCREEN_WIDTH  128
#define SCREEN_HEIGHT  64
#define OLED_ADDRESS  0x3C
#define OLED_RESET     -1

Adafruit_SSD1306 display(SCREEN_WIDTH, SCREEN_HEIGHT, &Wire, OLED_RESET);
bool oledReady = false;

// ===================== 손목 → 벨트 ESP-NOW =====================
// 브로드캐스트로 센서값 전송, 벨트가 유니캐스트 회신
const uint8_t BELT_BROADCAST_MAC[] = {0xFF, 0xFF, 0xFF, 0xFF, 0xFF, 0xFF};

typedef struct SensorPacket {
  int           bpm;
  float         temp;
  int           gsr;
  int           gsrDiff;
  long          ir;
  bool          finger;
  unsigned long seq;
} SensorPacket;

SensorPacket  sensorTxData;
unsigned long sensorSequence = 0;

// ===================== 벨트 → 손목 표시 결과 =====================
DisplayPacket beltDisplayData;
bool          beltDisplayReceived = false;
unsigned long lastBeltDisplayTime = 0;

// ===================== 센서 객체 =====================
MAX30105 particleSensor;
TMP117   tempSensor;

// ===================== 심박 =====================
const byte RATE_SIZE = 8;
byte          rates[RATE_SIZE];
byte          rateSpot      = 0;
byte          validRateCount = 0;
unsigned long lastBeat       = 0;
float         beatsPerMinute = 0.0f;
int           beatAvg        = 0;
long          irValue        = 0;

// ===================== GSR =====================
int gsrBaseline = 0;
int gsrValue    = 0;
int gsrDiff     = 0;

// ===================== 온도 =====================
float tempC = 0.0f;

// ===================== 타이밍 =====================
unsigned long lastTempRead      = 0;
unsigned long lastGsrRead       = 0;
unsigned long lastSerialPrint   = 0;
unsigned long lastMotorEvent    = 0;
unsigned long lastDisplayUpdate = 0;
unsigned long lastSensorSend    = 0;

const unsigned long TEMP_INTERVAL    = 1000;
const unsigned long GSR_INTERVAL     = 200;
const unsigned long SERIAL_INTERVAL  = 1000;
const unsigned long MOTOR_COOLDOWN   = 3000;
const unsigned long DISPLAY_INTERVAL = 500;
const unsigned long SENSOR_SEND_INTERVAL = 1000;
const unsigned long BELT_STATUS_TIMEOUT  = 3000;

// ===================== 임계값 =====================
const int IR_FINGER_THRESHOLD = 50000;
const int BPM_MIN_VALID       = 45;
const int BPM_MAX_VALID       = 180;

// ===================== 함수 =====================

int readGSRFiltered() {
  long sum = 0;
  const int samples = 10;
  for (int i = 0; i < samples; i++) {
    sum += analogRead(GSR_PIN);
    delay(2);
  }
  return (int)(sum / samples);
}

int calibrateGSRBaseline() {
  long sum = 0;
  const int samples = 50;
  Serial.println("Calibrating GSR... keep still.");
  for (int i = 0; i < samples; i++) {
    sum += readGSRFiltered();
    delay(50);
  }
  return (int)(sum / samples);
}

void vibrateMotor(int onTimeMs) {
  digitalWrite(MOTOR_PIN, HIGH);
  delay(onTimeMs);
  digitalWrite(MOTOR_PIN, LOW);
}

const char* displayCauseText(uint8_t cause) {
  switch (cause) {
    case CAUSE_HR_HIGH:   return "HR HIGH";
    case CAUSE_HR_CHANGE: return "HR CHANGE";
    case CAUSE_TEMP_UP:   return "TEMP UP";
    case CAUSE_GSR_UP:    return "GSR UP";
    case CAUSE_HOT_ENV:   return "HOT ENV";
    case CAUSE_ACTIVE:    return "ACTIVE";
    case CAUSE_SENSOR:    return "CHECK BODY";
    default:              return "CHECK BODY";
  }
}

bool beltStatusFresh() {
  return beltDisplayReceived &&
         (millis() - lastBeltDisplayTime < BELT_STATUS_TIMEOUT);
}

bool beltAlertActive() {
  if (!beltStatusFresh()) return false;

  return
    beltDisplayData.state == STATE_CAUTION ||
    beltDisplayData.state == STATE_COOLING ||
    beltDisplayData.state == STATE_EMERGENCY;
}

// ===================== ESP-NOW 수신 (벨트 → 손목) =====================
void onBeltDataRecv(
  const esp_now_recv_info_t *recv_info,
  const uint8_t             *incomingData,
  int                        len
) {
  if (len != sizeof(DisplayPacket)) return;

  DisplayPacket received;
  memcpy(&received, incomingData, sizeof(received));

  if (received.magic   != DISPLAY_PACKET_MAGIC ||
      received.version != DISPLAY_PACKET_VERSION) return;

  beltDisplayData      = received;
  beltDisplayReceived  = true;
  lastBeltDisplayTime  = millis();
}

// ===================== 센서값 전송 =====================
void sendSensorPacket(bool fingerDetected) {
  sensorTxData.bpm     = beatAvg;
  sensorTxData.temp    = tempC;
  sensorTxData.gsr     = gsrValue;
  sensorTxData.gsrDiff = gsrDiff;
  sensorTxData.ir      = irValue;
  sensorTxData.finger  = fingerDetected;
  sensorTxData.seq     = sensorSequence++;

  esp_now_send(
    BELT_BROADCAST_MAC,
    reinterpret_cast<const uint8_t *>(&sensorTxData),
    sizeof(sensorTxData)
  );
}

// ===================== OLED 업데이트 =====================
void updateDisplay() {
  if (!oledReady) return;

  display.clearDisplay();
  display.setTextColor(SSD1306_WHITE);
  display.setTextWrap(false);

  if (!beltStatusFresh()) {
    display.setTextSize(2);
    display.setCursor(0, 5);
    display.println("LINK LOST");

    display.setTextSize(1);
    display.setCursor(0, 38);
    display.println("CHECK BELT");

    display.setCursor(0, 52);
    display.println("ESP-NOW WAIT");

    display.display();
    return;
  }

  float temp =
    beltDisplayData.skinTemp_x100 / 100.0f;

  uint8_t coolingStage =
    displayGetCoolingStage(
      beltDisplayData.flags
    );

  // ---------------------------------------------------
  // line 1
  // ---------------------------------------------------
  display.setTextSize(2);
  display.setCursor(0, 4);

  switch (beltDisplayData.state) {
    case STATE_BOOT:
      display.println("BOOT");
      break;

    case STATE_BASELINE:
      display.println("BASELINE");
      break;

    case STATE_NORMAL:
      display.println("NORMAL");
      break;

    case STATE_CAUTION:
      display.println("CAUTION");
      break;

    case STATE_COOLING:
      if (coolingStage == COOLING_C3) {
        display.println("HIGH RISK");
      }
      else if (coolingStage == COOLING_C2) {
        display.println("DANGER");
      }
      else {
        display.println("COOLING");
      }
      break;

    case STATE_EMERGENCY:
      display.println("EMERGENCY");
      break;

    case STATE_SENSOR_CHECK:
      display.setTextSize(1);
      display.setCursor(0, 9);
      display.println("SENSOR CHECK");
      break;

    default:
      display.println("UNKNOWN");
      break;
  }

  // ---------------------------------------------------
  // line 2
  // ---------------------------------------------------
  display.setTextSize(1);
  display.setCursor(0, 36);

  switch (beltDisplayData.state) {
    case STATE_BOOT:
      display.println("STARTING");
      break;

    case STATE_BASELINE:
      display.println("STAY STILL");
      break;

    case STATE_NORMAL:
      display.print("HR ");
      display.print(beltDisplayData.bpm);
      display.print("  T ");
      display.print(temp, 1);
      display.println("C");
      break;

    case STATE_CAUTION:
      display.println(
        displayCauseText(
          beltDisplayData.cause
        )
      );
      break;

    case STATE_COOLING:
      if (coolingStage == COOLING_C1) {
        display.print("FAN 50% ");
      }
      else {
        display.print("FAN 100% ");
      }

      display.println(
        displayCauseText(
          beltDisplayData.cause
        )
      );
      break;

    case STATE_EMERGENCY:
      display.println("SOS FAN 100%");
      break;

    case STATE_SENSOR_CHECK:
      display.println("WEAR GLOVE");
      break;

    default:
      display.println("CHECK BELT");
      break;
  }

  display.display();
}

// ===================== SETUP =====================
void setup() {
  Serial.begin(115200);
  delay(1000);

  Wire.begin(I2C_SDA_PIN, I2C_SCL_PIN);

  // ESP-NOW
  WiFi.mode(WIFI_STA);
  if (esp_now_init() != ESP_OK) {
    Serial.println("ESP-NOW init failed");
    while (1);
  }

  esp_now_register_recv_cb(onBeltDataRecv);

  esp_now_peer_info_t broadcastPeer = {};
  memcpy(broadcastPeer.peer_addr, BELT_BROADCAST_MAC, 6);
  broadcastPeer.channel = 0;
  broadcastPeer.encrypt = false;

  if (esp_now_add_peer(&broadcastPeer) != ESP_OK) {
    Serial.println("ESP-NOW broadcast peer failed");
    while (1);
  }

  // OLED
  oledReady = display.begin(SSD1306_SWITCHCAPVCC, OLED_ADDRESS);
  if (!oledReady) {
    Serial.println("OLED init failed - continuing without display");
  } else {
    display.clearDisplay();
    display.setTextColor(SSD1306_WHITE);
    display.setTextSize(1);
    display.setCursor(0, 0);
    display.println("HEATSENTRY");
    display.println("STARTING");
    display.display();
  }

  // 모터
  pinMode(MOTOR_PIN, OUTPUT);
  digitalWrite(MOTOR_PIN, LOW);

  // ADC
  analogReadResolution(12);

  // TMP117
  if (!tempSensor.begin()) {
    Serial.println("TMP117 init failed");
    while (1);
  }

  // MAX30102
  if (!particleSensor.begin(Wire, I2C_SPEED_STANDARD)) {
    Serial.println("MAX30102 init failed");
    while (1);
  }
  particleSensor.setup(60, 4, 2, 100, 411, 4096);
  particleSensor.setPulseAmplitudeRed(0x2A);
  particleSensor.setPulseAmplitudeIR(0x2A);
  particleSensor.setPulseAmplitudeGreen(0);

  // GSR 베이스라인
  gsrBaseline = calibrateGSRBaseline();
  Serial.printf("GSR baseline = %d\n", gsrBaseline);

  vibrateMotor(120);
  Serial.println("System ready");
}

// ===================== LOOP =====================
void loop() {
  unsigned long now = millis();

  // ── MAX30102 심박 ─────────────────────────────
  irValue = particleSensor.getIR();
  bool fingerDetected = (irValue > IR_FINGER_THRESHOLD);

  if (fingerDetected) {
    if (checkForBeat(irValue)) {
      unsigned long delta = now - lastBeat;
      lastBeat = now;
      beatsPerMinute = 60.0f / (delta / 1000.0f);

      if (beatsPerMinute > BPM_MIN_VALID &&
          beatsPerMinute < BPM_MAX_VALID) {
        rates[rateSpot++] = (byte)beatsPerMinute;
        rateSpot %= RATE_SIZE;
        if (validRateCount < RATE_SIZE) validRateCount++;

        int sum = 0;
        for (byte i = 0; i < validRateCount; i++) sum += rates[i];
        beatAvg = sum / validRateCount;
      }
    }
  } else {
    beatsPerMinute = 0;
    beatAvg        = 0;
    validRateCount = 0;
  }

  // ── TMP117 온도 ──────────────────────────────
  if (now - lastTempRead >= TEMP_INTERVAL) {
    lastTempRead = now;
    tempC = tempSensor.readTempC();
  }

  // ── GSR ─────────────────────────────────────
  if (now - lastGsrRead >= GSR_INTERVAL) {
    lastGsrRead = now;
    gsrValue = readGSRFiltered();
    gsrDiff  = gsrValue - gsrBaseline;
  }

  // ── 센서값 → 벨트 전송 ──────────────────────
  if (now - lastSensorSend >= SENSOR_SEND_INTERVAL) {
    lastSensorSend = now;
    sendSensorPacket(fingerDetected);
  }

  // ── OLED 갱신 ────────────────────────────────
  if (now - lastDisplayUpdate >= DISPLAY_INTERVAL) {
    lastDisplayUpdate = now;
    updateDisplay();
  }

  // ── 진동 모터: 벨트 판정 결과에만 반응 ───────
  if (beltAlertActive()) {
    if (now - lastMotorEvent >= MOTOR_COOLDOWN) {
      lastMotorEvent = now;
      vibrateMotor(120);
      delay(120);
      vibrateMotor(120);
    }
  }

  // ── 시리얼 출력 ──────────────────────────────
  if (now - lastSerialPrint >= SERIAL_INTERVAL) {
    lastSerialPrint = now;
    Serial.printf(
      "Finger=%s  IR=%ld  BPM=%.1f  Avg=%d  Temp=%.2f  GSR=%d  Diff=%d  Alert=%s\n",
      fingerDetected ? "YES" : "NO",
      irValue, beatsPerMinute, beatAvg,
      tempC, gsrValue, gsrDiff,
      beltAlertActive() ? "YES" : "NO"
    );
  }
}

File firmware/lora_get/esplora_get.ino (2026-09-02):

#include "LoRaWan_APP.h"
#include "Arduino.h"

// =====================================================
// LoRa settings - Belt와 반드시 동일
// =====================================================
#define RF_FREQUENCY          922300000
#define LORA_BANDWIDTH        0
#define LORA_SPREADING_FACTOR 7
#define LORA_CODINGRATE       1
#define LORA_PREAMBLE_LENGTH  8
#define LORA_SYMBOL_TIMEOUT   0
#define LORA_FIX_LENGTH_PAYLOAD_ON false
#define LORA_IQ_INVERSION_ON       false

// =====================================================
// 35 byte packet
//
// version 2:
// airTemp_x10:
//   high = DeviceState
//   low  = Cause
//
// humidity_x10:
//   high = CoolingStage
//   low  = RiskIndex
// =====================================================
struct __attribute__((packed)) TelemetryPacket {
  uint16_t magic;
  uint8_t  version;
  uint8_t  nodeId;
  uint16_t seq;

  uint8_t  bpm;
  int16_t  skinTemp_x100;
  uint16_t gsr;
  int16_t  gsrDiff;
  uint32_t ir;

  int16_t  airTemp_x10;
  uint16_t humidity_x10;

  int32_t  latitude_e7;
  int32_t  longitude_e7;
  uint8_t  satellites;
  int16_t  altitude_dm;
  uint16_t speed_x10;

  uint8_t  flags;
};

static_assert(
  sizeof(TelemetryPacket) == 35,
  "TelemetryPacket must be 35 bytes"
);

TelemetryPacket rxData;
static RadioEvents_t RadioEvents;

const char* getStateName(uint8_t state) {
  switch (state) {
    case 0: return "BOOT";
    case 1: return "BASELINE";
    case 2: return "NORMAL";
    case 3: return "CAUTION";
    case 4: return "COOLING";
    case 5: return "EMERGENCY";
    case 6: return "SENSOR CHECK";
    default: return "UNKNOWN";
  }
}

const char* getCauseName(uint8_t cause) {
  switch (cause) {
    case 0: return "NONE";
    case 1: return "HR HIGH";
    case 2: return "HR CHANGE";
    case 3: return "TEMP UP";
    case 4: return "GSR UP";
    case 5: return "HOT ENV";
    case 6: return "ACTIVE";
    case 7: return "SENSOR";
    default: return "UNKNOWN";
  }
}

const char* getStageName(uint8_t stage) {
  switch (stage) {
    case 0: return "C0";
    case 1: return "C1";
    case 2: return "C2";
    case 3: return "C3";
    case 4: return "C4";
    default: return "C?";
  }
}

// Python bridge reads only this line.
void printRawPacket(
  const uint8_t *payload,
  uint16_t size,
  int16_t rssi,
  int8_t snr
) {
  Serial.print("HSRAW,");

  for (uint16_t i = 0; i < size; i++) {
    if (payload[i] < 0x10) {
      Serial.print("0");
    }

    Serial.print(
      payload[i],
      HEX
    );
  }

  Serial.print(",");
  Serial.print(rssi);
  Serial.print(",");
  Serial.println(snr);
}

void OnRxDone(
  uint8_t *payload,
  uint16_t size,
  int16_t rssi,
  int8_t snr
) {
  if (size != sizeof(TelemetryPacket)) {
    Serial.printf(
      "[ERROR] PACKET SIZE %u / expected %u\n",
      size,
      (unsigned)sizeof(TelemetryPacket)
    );

    Radio.Rx(0);
    return;
  }

  memcpy(
    &rxData,
    payload,
    sizeof(rxData)
  );

  if (rxData.magic != 0xA55A) {
    Serial.println(
      "[ERROR] INVALID MAGIC"
    );

    Radio.Rx(0);
    return;
  }

  // Dashboard bridge raw packet
  printRawPacket(
    payload,
    size,
    rssi,
    snr
  );

  uint16_t stateCauseWord =
    (uint16_t)rxData.airTemp_x10;

  uint8_t stateCode =
    (uint8_t)(
      (stateCauseWord >> 8) & 0xFF
    );

  uint8_t causeCode =
    (uint8_t)(
      stateCauseWord & 0xFF
    );

  uint16_t stageRiskWord =
    rxData.humidity_x10;

  uint8_t coolingStage =
    (uint8_t)(
      (stageRiskWord >> 8) & 0xFF
    );

  uint8_t riskIndex =
    (uint8_t)(
      stageRiskWord & 0xFF
    );

  bool gloveValid =
    rxData.flags & (1 << 0);

  bool gpsValid =
    rxData.flags & (1 << 2);

  bool finger =
    rxData.flags & (1 << 3);

  bool emergency =
    rxData.flags & (1 << 4);

  bool fanOn =
    rxData.flags & (1 << 5);

  Serial.println();
  Serial.println(
    "================================="
  );

  Serial.println(
    " DASHBOARD RECEIVED"
  );

  Serial.println(
    "================================="
  );

  Serial.printf(
    "Bytes         : %u\n",
    size
  );

  Serial.printf(
    "RSSI / SNR    : %d dBm / %d dB\n",
    rssi,
    snr
  );

  Serial.println();
  Serial.println("[ SYSTEM ]");

  Serial.printf(
    "Version       : %u\n",
    rxData.version
  );

  Serial.printf(
    "Node ID       : %u\n",
    rxData.nodeId
  );

  Serial.printf(
    "Sequence      : %u\n",
    rxData.seq
  );

  Serial.printf(
    "Flags         : 0x%02X\n",
    rxData.flags
  );

  Serial.println();
  Serial.println("[ FSM ]");

  Serial.printf(
    "State         : %s\n",
    getStateName(stateCode)
  );

  Serial.printf(
    "CoolingStage  : %s\n",
    getStageName(coolingStage)
  );

  Serial.printf(
    "Cause         : %s\n",
    getCauseName(causeCode)
  );

  if (riskIndex <= 100) {
    Serial.printf(
      "RiskIndex     : %u\n",
      riskIndex
    );
  }
  else {
    Serial.println(
      "RiskIndex     : INVALID"
    );
  }

  Serial.println();
  Serial.println("[ BELT ]");

  Serial.printf(
    "Emergency     : %s\n",
    emergency
      ? "ACTIVE"
      : "NORMAL"
  );

  Serial.printf(
    "Fan           : %s\n",
    fanOn
      ? "ON"
      : "OFF"
  );

  Serial.println();
  Serial.println("[ GLOVE / ESP32U ]");

  if (gloveValid) {
    Serial.printf(
      "BPM           : %u\n",
      rxData.bpm
    );

    Serial.printf(
      "Skin Temp     : %.2f C\n",
      rxData.skinTemp_x100 / 100.0f
    );

    Serial.printf(
      "GSR           : %u\n",
      rxData.gsr
    );

    Serial.printf(
      "GSR Diff      : %d\n",
      rxData.gsrDiff
    );

    Serial.printf(
      "IR            : %lu\n",
      rxData.ir
    );

    Serial.printf(
      "Finger        : %s\n",
      finger
        ? "YES"
        : "NO"
    );
  }
  else {
    Serial.println("NO GLOVE DATA");
  }

  Serial.println();
  Serial.println("[ GPS ]");

  if (gpsValid) {
    Serial.printf(
      "Latitude      : %.6f\n",
      rxData.latitude_e7 / 10000000.0
    );

    Serial.printf(
      "Longitude     : %.6f\n",
      rxData.longitude_e7 / 10000000.0
    );

    Serial.printf(
      "Satellites    : %u\n",
      rxData.satellites
    );

    Serial.printf(
      "Altitude      : %.1f m\n",
      rxData.altitude_dm / 10.0f
    );

    Serial.printf(
      "Speed         : %.1f km/h\n",
      rxData.speed_x10 / 10.0f
    );
  }
  else {
    Serial.printf(
      "NO GPS FIX (Satellites: %u)\n",
      rxData.satellites
    );
  }

  Serial.println(
    "================================="
  );

  Radio.Rx(0);
}

void OnRxTimeout() {
  Radio.Rx(0);
}

void OnRxError() {
  Serial.println("[LoRa] RX ERROR");
  Radio.Rx(0);
}
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

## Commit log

2026-08-08 전체파이프라인정리
2026-09-01 refactor: reorganize HeatSentry TAC structure
    [01_LEFT_SHELL_V7.step, 01_LEFT_SHELL_V7.stl, 02_RIGHT_SHELL_V7.step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]
2026-09-01 risk index 수정
2026-09-02 chore: 중복·미사용 파일 제거
    - docs/hardware.zip: docs/hardware/ 디렉터리와 내용이 동일한 2.1MB 중복 아카이브
    - docs/hardware/cad/docs: 1바이트 빈 파일
    - firmware/glove_esp32/display_messages.py: algorithm/display_status.py와
    바이트 단위로 동일한 복사본. 표시 문구 규칙이 두 곳에 있으면 한쪽만 고쳐질 수 있다
    - dashboard/README.md: Vite 템플릿 기본 문서. 루트 README가 대시보드 실행법을 다룬다
    - dashboard/{public/icons.svg, src/assets/*}: 어디에서도 참조되지 않는 템플릿 잔여물
2026-09-02 refactor(fsm): 냉각 단계 임계값을 risk_config 표 하나로 일원화
    FsmConfig.stages에 C0~C4의 진입/해제 임계값과 팬 출력이 전부 정의돼 있는데도
    fsm.py가 80/90/10/60/30을 하드코딩하고 있어, 표는 읽히지 않는 죽은 설정이었다.
    같은 이유로 팬 출력표(_STAGE_FAN)와 단계 순번표(_STAGE_INDEX)가 세 파일에
    복제돼 있었다. risk_config.py 첫 줄의 "이 파일 하나만 바꾸면 되도록" 원칙대로
    되돌린다.
    - fsm.py: 승급/강등/팬 출력을 모두 cfg.stages에서 유도. 임계값별 HoldTimer를
    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
2026-09-02 refactor: 파이썬 코드를 heatsentry 패키지로 통합하고 파일 위치 정리
    파이썬 시뮬레이터가 임베디드 C/C++ 펌웨어 폴더(firmware/) 안에 들어가 있고,
    최상위에 common/ algorithm/ server/ 가 흩어져 있어 무엇이 배포 단위인지
    저장소 루트만 봐서는 알 수 없었다. 파이썬은 heatsentry/ 하나로 모으고,
    그 바깥에는 파이썬이 아닌 것만 남긴다.
    이동 (git mv로 이력 보존):
    - common/ -> heatsentry/common/
    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
2026-09-02 docs: README 저장소 구조에 firmware/lora_get 추가
    LoRa 수신기 스케치가 새로 들어왔으므로 구조도에도 반영한다. 이 스케치가
    시리얼로 넘기는 35바이트 TelemetryPacket을 heatsentry/server/lora_adapter.py가
    관제용 TelemetryV2로 변환한다.
2026-09-02 feat: 팀원 펌웨어 변경(DHT 제거·벨트 판정 전송)을 파이썬·문서에 반영
    팀원이 올린 벨트/장갑 펌웨어가 35바이트 패킷의 의미를 바꿨는데 파이썬 쪽은
    옛 해석을 그대로 하고 있었다. 세 가지가 어긋나 있었다.
    1. airTemp_x10 필드 용도 변경
    DHT11이 팬 동작 중 읽기 실패를 반복해 하드웨어에서 제거됐고, 펌웨어는 빈
    16비트 자리를 자기 상태·원인 코드 전송에 재활용한다
    (txData.airTemp_x10 = (state << 8) | cause). 디코더는 이를 아직 기온으로
    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
2026-09-02 docs: 벨트 팬 제어 변경(e5b5842) 반영 및 낡은 FSM 절 갱신
    팀원이 팬 제어를 두 채널 개별 제어로 바꿨다. 냉각 1단계가 "PWM 듀티 50%"가
    아니라 "팬 2개 중 1개만 100%"가 됐고, 손목 데이터 유효 시간도 5초에서 10초로
    늘었다. 배선 계약은 그대로라 파이썬 코드는 영향이 없다(시험 76건 통과).
    - hardware_integration_kr.md 9.2절이 두 세대 전 펌웨어를 설명하고 있었다.
    30.0/29.0°C 온도 임계 MVP, 부팅 후 3초 BOOT 분기, STATE_WARNING — 현재
    코드에 전부 존재하지 않는다. 실제 calculateRisk() 가산식(BPM/피부온도/GSR)과
    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
2026-09-03 chore: 불필요한 주석 정리 및 대시보드 env 예시 복구
    - auth.py에 남아 있던 개발 도구용 메모 문구 제거, 경고 내용은 유지
    - 한글 코드베이스에 영어로 남아 있던 주석을 한글로 통일 (main.py)
    - 리팩터 과정을 서술하던 주석 제거 (main.py, run_demo.py,
    common/__init__.py, wrist_node.py)
    - hardware_adapter.py docstring 축약
    - 내용이 비어 있던 dashboard/.env.example 복구 및 VITE_GATEWAY_URL 추가
2026-09-03 fix: 상태 모델 통일 이후 깨진 테스트 복구 및 FSM 단계 하드코딩 제거
    상태 코드 통일(BeltStateCode -> DeviceStateCode + CoolingStageCode)과
    DHT 제거가 테스트에 반영되지 않아 76건 중 16건이 수집 단계에서 실패하고
    4건이 오류로 남아 있었다.
    - test_glove_packets: state_cause_word / stage_risk_word 분리 반영,
    사라진 DHT 복원 경로 대신 냉각 단계·벨트 위험도 디코딩을 검증
    - test_lora_adapter: 게이트웨이가 재판정하지 않고 벨트 판정을 그대로
    전달하는 현재 구조에 맞춰 재작성. BELT_STATE_MISMATCH 대신
    STATE_INVALID / RISK_INVALID / COOLING_STAGE_INVALID를 검증
    -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
2026-09-03 docs: README 전면 개편 및 통일된 상태 모델 반영
    제출본 기준으로 README를 다시 썼다. 배경·시스템 구성·실행 방법·알고리즘·
    API·안전 경계·팀 정보를 코드에서 검증한 값으로 채웠다.
    상태 코드 통일(BeltStateCode -> DeviceStateCode + CoolingStageCode)에 맞춰
    FSM 절을 다시 썼다. 벨트와 게이트웨이가 각각 판정하고 불일치를 검출하던
    구조가 "벨트 단독 판정 + 게이트웨이 전달"로 바뀌었으므로, 이중 판정 서술을
    걷어내고 해석 불가 값 처리(STATE_INVALID / COOLING_STAGE_INVALID /
    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
2026-09-03 docs: 설계 문서 정리 — hardware 가이드만 남김
    concept / architecture / ai_pipeline / api_contract / demo_scenario /
    aar_design을 삭제했다. 기준선 문서(HS-PDD-002, HS-SIID-002)와 README가
    같은 내용을 중복해 담고 있어, 코드가 바뀔 때마다 세 곳을 맞춰야 했다.
    README의 링크를 실제 근거 코드로 돌리고, 설계 문서 표를 "대상 -> 코드"
    매핑으로 대체했다. hardware_integration_kr.md의 상호참조도 함께 정리했다.
